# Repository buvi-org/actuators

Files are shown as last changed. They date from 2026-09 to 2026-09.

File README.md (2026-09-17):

# Primeform Robotics Actuators

We are designing and building actuators for the Primeform Robotics division, and we are doing the work in public.

This repository will hold our actuator designs and the work behind them so they are useful to our team and to others building robotics systems. As each design develops, we plan to share design files, engineering calculations, bills of materials, assembly instructions, and test results.

## Development approach

- Share work as it develops, including early designs and experiments.
- Document design decisions, tradeoffs, and lessons from testing.
- Distinguish proposed designs from built and tested hardware.
- Welcome questions, feedback, and contributions through GitHub issues and pull requests.

## AK80-9 V3.0 KV100 reference study

Our first actuator study uses the CubeMars AK80-9 V3.0 KV100 as a reference. It is an outer-rotor motor with a 9:1 planetary reducer and integrated electronics. Published CubeMars performance is a reference target, not validated performance of a Primeform build.

The Three.js workbench includes:

- A full BOM tree with selection, hierarchical visibility, isolation, focus, and a details inspector showing specifications, sources, and unresolved information.
- The manufacturer reference contains 43 CAD instances. The combined study replaces its sun blank with one gear-and-shaft solid and adds provisional stator laminations, coating faces, winding bundles, rotor yoke, magnets, gears, pins and electronics. Manufacturer bearings and fasteners remain selectable.
- An **Internals** preset and a **Gear train** preset that exposes a toothed sun, three planets and the internal ring. The 20/70/160 tooth counts produce exactly 9:1 with the ring fixed; all three gear types use involute flanks from the STEP solids. The candidate module is 0.3 and pressure angle 20°. Manufacturing release still requires process, tolerances and strength validation.
- A Primeform housing variant with screw bosses extended to the floor, a downloadable solid STEP, and a visible warning for the measured clash with the provisional rotor yoke. Toggle the gold support material to compare the source housing. See [housing study](docs/HOUSING-STUDY.md).
- Choice C: a compact ring OD locates a Ø60-bore stator radially; a housing shoulder stops it axially. [Alternatives and decision](docs/PACKAGING-CHOICES.md). **Stator mount** exposes the joint; see [mounting design and checks](docs/STATOR-MOUNT.md).
- Single-solid sun, planet and ring gear STEP files; a gear-train STEP with five gear components (one sun, three planets, one ring). Teeth are integral geometry, never assembly components. The sun preserves source end journals and replaces its middle section; its viewer mesh is tessellated from that same solid. Rebuild with `python cad/build_gears.py`; the viewer uses meshes tessellated from the same solids.
- Full assembly GLB export, including reference geometry and annotated provisional bodies. The separate Lamination lab remains independently configurable; its settings do not currently change the assembly study.
- A 35-line engineering BOM distinguishing source CAD, published data, illustration inferences and unresolved items. External mating cables are documented under the power/CAN and UART connectors, without separate internal BOM quantities or cable geometry.
- An inventory of 205 driver-board reference designators and package-model labels. Component values and exact IC part numbers remain unknown. These inventory entries are selectable data records; individual PCB positions are not mapped to the actuator assembly, so their visibility controls are disabled.
- An original, provisional lamination study with individually selectable steel sheets and two coating layers per sheet, editable profile dimensions, coating/gap/tolerance calculations, and live study quantities.
- GLB, DXF, JSON and default solid STEP deliverables.

**This is a reference and design study, not a manufacture-ready AK80-9 clone.** The manufacturer STEP omits the working motor stack and planetary internals. The lamination profile is an independently authored placeholder; only its default 36-slot count comes from the manufacturer specification.

### Run the workbench

Requires Node.js 22.12+ or a compatible newer release (tested with Node 24).

```sh
npm ci
npm run dev
```

Open `http://127.0.0.1:5173/`. Use `#lamination` to open the individual-sheet study directly. The viewer uses local Three.js/model assets; Google Fonts is optional and falls back to system fonts.

```sh
npm test
npm run build
npm run preview
```

Browser interaction checks: run the dev server, then `npm run test:browser`. The default browser is installed Microsoft Edge; set `BROWSER_CHANNEL=chrome` to use Chrome. Test outputs stay in ignored `tmp/qa/`.

### Design and evidence files

| Item | Location |
|---|---|
| Engineering BOM | [docs/BOM.md](docs/BOM.md) |
| Per-component specifications | [docs/COMPONENT-SPECS.md](docs/COMPONENT-SPECS.md) |
| Internal structure findings and questions | [docs/INTERNAL-STRUCTURE.md](docs/INTERNAL-STRUCTURE.md) |
| Electronic reference-designator inventory | [docs/DRIVER-INVENTORY.md](docs/DRIVER-INVENTORY.md) |
| Lamination equations and manufacturing limits | [docs/LAMINATION-STUDY.md](docs/LAMINATION-STUDY.md) |
| Source register and attribution | [docs/SOURCES.md](docs/SOURCES.md) |
| Reference GLB and part manifest | [public/models/](public/models/) |
| Original provisional sheet and stack STEP/DXF | [public/design/](public/design/) |
| Machine-readable BOM and specifications | [public/data/](public/data/) |

### Rebuild CAD and engineering data

Python 3.11 is tested. Install CAD dependencies in your chosen environment:

```sh
python -m pip install -r cad/requirements.txt
python cad/build_reference.py
python cad/extract_driver_inventory.py
python scripts/build_bom.py
npm run lamination
```

The first two commands download the manufacturer's ZIP files into ignored `tmp/reference/`. The conversion preserves source occurrence IDs, records the STEP hash, transforms the assembly to a centred coordinate system and converts millimetres to metres for GLB. Visual colours and explosion offsets are our annotations.

To make solid CAD for a changed lamination configuration, export **Study JSON** from the webview, then run:

```sh
python cad/build_lamination.py path/to/lamination-study.json
```

This updates the generated STEP files in `public/design/`. Browser **Stack GLB** always exports the current full assembly at true thickness, independent of display spread or the selected-sheet view. It uses metres; STEP and DXF use millimetres.

See [involute gear design and manufacturing release requirements](docs/GEAR-DESIGN.md) for the matched candidate, equations, checks and unresolved inputs.

## Licensing

The repository is public. Licenses for Primeform's hardware studies, software and documentation have not yet been selected; public access alone does not grant a license to reuse those materials. Manufacturer reference geometry remains attributed to CubeMars. It is not an original Primeform design or covered by a Primeform open-hardware license. See [source attribution](docs/SOURCES.md).

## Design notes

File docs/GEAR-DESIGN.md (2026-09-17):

# Involute planetary candidate — 9:1

This replaces the polygonal placeholder teeth with an analytically defined involute candidate. It is an original Primeform gear design, not a recovered CubeMars tooth specification. Manufacturing release is pending; a CAD curve cannot establish 100% physical manufacturing accuracy.

| Parameter | Sun | Planet (three) | Internal ring |
|---|---:|---:|---:|
| Teeth | 20 | 70 | 160 |
| Module, mm | 0.3 | 0.3 | 0.3 |
| Pressure angle | 20° | 20° | 20° |
| Profile shift | 0 | 0 | 0 |
| Pitch diameter, mm | 6 | 21 | 48 |
| Tip diameter, mm | 6.6 | 21.6 | 47.4 |
| Root diameter, mm | 5.25 | 20.25 | 48.75 |
| Face width, mm | 7.5 | 5 | 5 |
| Circular tooth thinning, mm | 0.010 | 0.010 | 0.010 |

The candidate preserves the previous pitch diameters and 13.5 mm planet centre radius. The standard unshifted 20° undercut limit is 2/sin²(20°) ≈ 17.10 teeth; the 20-tooth sun clears it. The previous 12-tooth sun did not, and cannot simply be given an unshifted full-depth involute without addressing undercut.

With the ring fixed, sun input and carrier output, i = 1 + Zr/Zs = 1 + 160/20 = 9 exactly. Geometry closes because Zr = Zs + 2Zp = 160. Three equally spaced planets are possible because (Zs + Zr)/3 = 60 is an integer. Changing which member is fixed changes the ratio.

## Curves and STEP

`cad/involute_geometry.py` defines the flanks from the involute function, inv(alpha) = tan(alpha) - alpha, and the base radius. Each flank uses a parameterized interpolating B-spline with 49 analytic samples; 193 independent evaluation positions per representative flank check the fit. The enforced sampled position-error bound is 0.000001 mm. This is a numerical CAD check, not a manufacturing tolerance or a rigorous bound between every sample. STEP uses curved edges, not polygonal tooth flanks.

Root transitions use 0.060 mm circular fillets. The sun includes the below-base-circle radial transition; the planet and ring use tangent circular root blends. These fillets are explicitly designed geometry, not a claim about the trochoidal root left by a hob or shaper. A cutting process/tool definition may require different roots. Tip relief, lead correction and crowning are not yet specified.

Each gear is one valid solid. The sun preserves the source end journals, replacing the central section from z = 3.75 to 11.25 mm. The common mesh plane is z = 8.25 mm. STEP files are exported and re-imported to verify validity, solid count and volume. The browser loads tessellations of the same solids for all three gear types. The manufacturing surface is the STEP B-rep, not the GLB triangles.

## Checks and their limits

`public/design/gear-validation.json` records solid and spline-fit checks. `public/design/gear-mesh-validation.json` records:

- Exact 9:1 kinematic ratio and matching 13.5 mm centre distances.
- External transverse contact ratio ≈ 1.682; internal ≈ 1.947, from standard unmodified addendum geometry.
- Correct planet/ring phasing and zero detected overlap in 720 sampled positions across one full carrier revolution (nine sun revolutions), using sampled actual CAD boundaries.
- Nominal 0.020 mm circular backlash per mesh, obtained by thinning each mating tooth by 0.010 mm at its pitch circle. This is a candidate nominal allowance, not a backlash tolerance range or a verified output lost-motion figure.

The motion check is finite planar sampling, not proof at every continuous position, cutter simulation, or loaded contact analysis. It excludes carrier/pin deflection, runout, tolerance stacks, temperature, lubrication and torque-dependent elastic deformation. The existing housing/rotor conflict remains separately unresolved.

## Required before manufacturing release

Choose cutting process, tooling and root generation; material and heat treatment; tooth-thickness/space-width tolerances and measurement method; gear quality, profile/lead deviations and runout limits; bearing and shaft fits; chamfers and burr removal; lubricant; rated/peak duty and life. Complete tooth bending/contact fatigue, load sharing, shaft/root/fillet strength, cutter interference, and loaded contact checks. The original product's torque ratings do not validate this finer-module candidate.

Rebuild: `python cad/build_reference.py` if source cache is absent, then `python cad/build_gears.py` and `python cad/check_gear_mesh.py`.

Sources: [Drivetrain Hub — spur gear geometry](https://drivetrainhub.com/notebooks/gears/geometry/Chapter%202%20-%20Spur%20Gears.html), [planetary assembly conditions](https://drivetrainhub.com/notebooks/gears/geometry/Chapter%204%20-%20Planetary%20Gears.html), [KHK — internal gear interference](https://khkgears.net/pdf/internal-tech.pdf). Equations were checked against these references; the candidate values are Primeform assumptions.

The ring now uses a compact Ø59.96 locating rim without the long stator sleeve; see [stator mounting revision](STATOR-MOUNT.md). The tooth geometry and ratio are unchanged.

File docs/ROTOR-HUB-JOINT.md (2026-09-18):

# Rotor hub / end bell joint audit — measurement record

Prepared 2026-09-17 against baseline `dd09154`. Reproduce with:

```powershell
python cad/check_hub_joint.py
```

Output: `public/design/hub-joint-validation.json`. Source geometry is the
manufacturer STEP revision recorded by `manifest.source_sha256`; the checker
asserts that hash before measuring, so these numbers cannot silently drift from
the reference model.

This replaces the arithmetic in the handoff. Everything below is a measurement of
the source CAD in the assembled, centred millimetre frame, or an explicit
statement that the measurement is impossible with the current modelled geometry.

## 1. What the OEM input-shaft hub actually is

Occurrence `NAUO45` (`AK80-9输入轴-2`), mapped in the BOM as `G03` "Input shaft
hub". Measured, it is **a body of revolution about the motor axis**, not a disc
with a bore. The X-Z material section is:

| z range (mm) | material radius (mm) | feature |
|---|---|---|
| -9.250 … -8.750 | 3.0, 5.55 … 5.95 | rear lead-in |
| -8.750 … -6.750 | 3.0, 6.0 | rear land, Ø6 bore |
| -6.750 … -3.250 | 2.0, 6.0 | Ø4 bore, Ø12 outer |
| -3.250 … -2.750 | 2.0, 7.0 | Ø14 shoulder |
| -2.750 … -1.750 | 2.0, 17.145 | flange back face, Ø34.29 |
| -1.750 … +0.250 | 2.0, 18.975, 21.025, 22.25 | spoked flange: Ø35.5 pocket, Ø42.05 rim, Ø44.5 outer |
| +0.250 … +1.250 | 2.0, 7.0 | Ø14 collar |
| +1.250 … +3.250 | 2.0, 6.0 | front land |
| +3.250 … +4.750 | 2.975, 6.0 | front counterbore Ø5.95 |
| +4.750 … +5.250 | 2.975, 5.55 … 5.95 | front lead-in |

Key numbers:

- Outer envelope Ø44.5, length 14.5 mm, volume 3114.2 mm³ (matches the manifest).
- Flange: r 17.145 → 22.25 mm (Ø34.29 → Ø44.5) over z -1.75 → +0.25 mm, so the
  web is **2 mm thick** with six spokes, a Ø35.5 annular pocket and a Ø42.05 rim.
- Bores: a 12 mm counterbore (see below), a Ø4 middle bore, a Ø6 rear bore and a
  Ø5.95 front counterbore.
- A Ø2.546 mm cylindrical face runs z -6.75 → +3.25 mm: the through-bore.

## 2. It is coaxial with the sun and carries both bearings

Boolean interference against the neighbouring occurrences (mm³):

| pair | interference | reading |
|---|---:|---|
| hub `NAUO45` ↔ sun `NAUO41` | 0.324 | coaxial, nominal line-to-line contact only |
| hub ↔ 6701-ZZ rear `NAUO42` | 0.000 | coaxial, no interpenetration |
| hub ↔ 6701-ZZ front `NAUO43` | 0.000 | coaxial, no interpenetration |
| hub ↔ encoder target magnet `NAUO44` | 0.000 | coaxial, no interpenetration |
| hub ↔ rear housing `NAUO4` | 0.000, min distance 0.500 | clears the housing |
| hub ↔ main housing `NAUO3` | 0.000 | clears the housing |

The STEP hierarchy confirms the grouping: one subassembly holds `NAUO41` (sun),
`NAUO42`/`NAUO43` (both 6701-ZZ), `NAUO44` (encoder magnet) and `NAUO45` (hub).
The hub is the bearing carrier of that coaxial module. It is **not** an outboard
end-bell disc that a hub bolts onto.

## 3. Why assembly step A06 attaches nothing

The viewer's rotor shell is procedural and does not share this form.

| | procedural `EM03/endbell` | measured OEM hub |
|---|---|---|
| form | plain annulus | body of revolution, six-spoke flange |
| opening / envelope | 46 mm opening (r 23) | Ø44.5 envelope (r 22.25) |
| z band | -8.6 … -7.6 mm | flange at -1.75 … +0.25 mm |

Three independent defects, each sufficient on its own:

1. **No contact.** The end-bell band and the hub flange band do not intersect in
   z at all — they are 6.85 mm apart at the nearest faces.
2. **No receiving surface.** Even if the two were brought into one plane, a 46 mm
   opening cannot receive a 44.5 mm body as a fit; the end bell has no bore, land,
   shoulder or counterbore sized for the hub.
3. **Wrong form.** The OEM part is a revolution body with a spoked flange; the
   procedural part is a flat annulus. Replacing one with the other is a geometry
   change, not a dimension tweak.

The rotor shell is not joined to itself either: `EM03/endbell` ends at z -7.6 mm
and `EM03/yoke` begins at z -7.5 mm, a modelled 0.1 mm axial gap. Sharing parent
`EM03` in the tree connects nothing.

**Conclusion.** A06 previously read "Attach input hub to rotor end bell" with
status "Proposed / requires validation". No attachment geometry, retention or
torque path existed. It is now marked `Blocked by known geometry`, and autoplay
stops on it instead of overshooting to A07.

## 4. The drive interface the CAD does encode

Sectioning the sun across the contact band and classifying each section (plain
loop vs azimuthal radius spread vs loop count) resolves the earlier open question:

| Measurement | Value |
|---|---|
| Contact volume | 0.324 mm³ |
| Contact axial band | z 3.750 … 5.250 mm |
| Fit at that band | sun front journal Ø6.000 into hub counterbore Ø5.950 |
| Sun section across the band | one loop, r 2.4185 … 3.000 |
| Azimuthal radius spread | **0.2022 mm** → a keyed or flat (D) drive feature |

So the hub does not merely retain the sun on bearings: its front counterbore
pilots the sun's keyed front journal over 1.5 mm of engagement. That is the
measured torque path from the rotor side into the sun, and it is why the earlier
"friction through two bearings" reading in this document was wrong.

**Caveat.** A 0.202 mm azimuthal spread measured from a CAD tessellation is
evidence of a drive feature, not a released key or spline specification. Confirm
it against hardware before designing to it.

No key, keyway, spline or cross-pin appears anywhere on the sun's rear Ø4.0
section.

## 5. What was implemented

1. **The real hub is in the model.** `cad/build_hub.py` re-exports occurrence
   `NAUO45` from the source STEP as `public/design/oem-rotor-hub.step` and
   `public/design/oem-rotor-hub.glb` (one valid solid, 3114.2 mm³, Ø44.5 × 14.5).
   The viewer shows it as assembly item `G03`, replacing the procedural
   `EM03/endbell` and `EM03/yoke` annuli, which have been deleted.
2. **The hub joint is described from measurement.** Assembly step A06 now names
   the actual surfaces: the Ø5.95 counterbore onto the sun's Ø6.0 keyed journal
   over z 3.75…5.25 mm, plus the Ø12 and Ø6 bearing bores and the encoder-magnet
   seat.
3. **The stator shift was reversed.** The rotor's axial position is fixed by real
   OEM features (the hub, both 6701-ZZ bearings, the encoder magnet), so the
   Choice C **+4.5 mm stator shift was the error**. The stator, winding, ring
   mounting flange and housing seat all moved 4.5 mm rearward, so the 13.872 mm
   steel stack now spans z −6.936…+6.936 mm and overlaps the full magnet span
   (−7…+7 mm) instead of 9.436 mm. The gear mesh itself is deliberately unchanged:
   the sun stays on the OEM shaft journals.
4. **Reports and data were regenerated**, not hand-edited: `build_gears.py` and
   `build_housing.py` now derive everything from a single `SHIFT` constant, and
   `stator-mount-validation.json`, `housing-study.json` and
   `packaging-choice.json` follow.

## 6. What is still blocked, and why

A06 remains `Blocked by known geometry`, for a different and better-understood
reason than before.

The hub's flange ends at **r 22.25 mm**. The nearest housing wall is at
**r 47.4 mm**. That is a **25.15 mm radial gap**, and the source CAD contains no
web, spider, bell or disc joining the hub to the rotor shell. So:

- The hub **is** measured, correctly shaped and correctly placed.
- The **hub-to-sun joint is real** and measured.
- The **hub-to-rotor-shell joint does not exist in the evidence**. Until it is
  designed, the hub has no rotor torque input and A07 has no rotor to install.

Two further open items:

1. **Rotor radial placement.** The study yoke (r 42.5…45.5) and magnet band
   (r 40.5…42.5) do not coincide with the arcuate slots in the source housings
   (r 41.766…43.236). The housings' slots do not match the study's 42-segment
   band either, so the source model does not settle where the magnets belong.
2. **The housing-boss clash.** The added supports still intersect the provisional
   yoke by 1134.581 mm³. It is unchanged by the axial realignment, because the
   yoke spans z −7.5…+7.5 and the supports run the housing floors.

## 7. Next correction, in order

1. Design and validate the hub-to-shell connection that closes the 25.15 mm gap,
   or establish from hardware that the OEM achieves it with a feature absent from
   the published STEP.
2. Resolve the rotor radial envelope so the yoke clears the housing bosses and the
   magnets sit on a justified radius.
3. Release the Ø5.95/Ø6.0 keyed pilot fit: fit class, retention, runout, balance
   and torque capacity against the 9:1 gearbox input.

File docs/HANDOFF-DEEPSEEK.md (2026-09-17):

# Handoff to DeepSeek — Primeform actuator CAD and assembly viewer

Prepared 2026-09-17. Technical baseline commit: `332871a` on `main`.

## Read this first

The user is dissatisfied with the mechanical reasoning and validation. They are handing this work over, not asking for more cosmetic changes from the previous agent. The latest concrete failure is **Assembly process step 6: the input shaft hub is suspended inside the rotor end bell with no modeled connection**. The previous agent had just begun investigating it when the user requested this handoff. No corrective geometry, contact measurement, or full visual audit was completed after that complaint.

The project is **not a mechanically complete actuator**, despite having a substantial viewer, BOM, generated STEP files, and passing software tests. Several parts are illustrative proxies. “Proposed / requires validation” labels do not excuse physically meaningless assembly operations. Do not treat the current sequence, zero-overlap checks, or valid STEP solids as proof of assemblability.

Working tree was clean at handoff start. This handoff is the only intended new change after baseline `332871a`.

## Project and environment

- User: Rajesh. Organization: Primeform Robotics; public engineering repository under buvi-org.
- Repository: https://github.com/buvi-org/actuators
- Windows workspace: `C:\Users\Rajesh\Documents\ChatGPT\actuators`
- Branch: `main`; previous work committed and pushed directly there with the user's prior authorization.
- Viewer: http://127.0.0.1:5173/#model (Vite server has been running locally; check before starting another).
- Frontend: Vite 8.3.0, Three.js 0.186.0, plain JavaScript.
- Node 24 was used. Python 3.11 with CadQuery 2.7.0, trimesh 4.11.2, shapely 2.1.2, scipy and numpy; see `cad/requirements.txt`.
- Playwright 1.58.2 tests use installed Microsoft Edge (`channel: msedge`).
- `tmp/`, `node_modules/`, `dist/`, Python caches and `.venv/` are ignored. Local diagnostic files in `tmp/` are not portable repository dependencies.

## User's objective and requirements

Create an open AK80-9 V3.0 KV100 actuator design for Primeform Robotics: complete physical assembly, individual laminations/coatings, gears, rotor, stator, windings, magnets, bearings, fastening, BOM/specifications and Three.js visualization. Internal assumptions must be distinguished from manufacturer evidence.

Persistent user requirements:

1. Preserve CubeMars external dimensions and mounting interfaces. Do not solve internal problems by arbitrarily enlarging the exterior or drastically thinning one feature.
2. Every physical part must be selectable and visibility-controlled through the BOM tree, with all known details in the inspector.
3. Each gear is one physical part and one STEP solid. Teeth are not separate tree items or separate manufactured parts.
4. Individual laminations must be represented; allow steel/coating/stack-count studies.
5. Do not add duplicate external harnesses when connectors already represent the interface.
6. Assembly steps must say exactly which part is fitted to which receiving part, on which surfaces, and by what process.
7. Parts must not pass through other solid parts. Treat subassemblies as retained groups once their connections exist.
8. Call the mode **Assembly process**, not Joint review.
9. Parts are opaque and have distinct, stable colors. No section cuts inside Assembly process.
10. Earlier installed parts stay visible; separate bench preparation retains earlier members of that subassembly.
11. Step navigation/playback must preserve camera orbit, pan and zoom. Only explicit Fit step (or ordinary viewer Fit) reframes.
12. Inspect actual rendered outputs and mechanical interfaces, not only code and UI assertions.

## Immediate failure: step A06, hub to rotor end bell

Current A06 says “Attach input hub to rotor end bell,” but no attachment geometry or method is implemented.

- G03 is OEM reference occurrence `NAUO45`, one source solid. Manifest bounding box in assembly mm: x/y ±22.25; z -9.25 to +5.25. Envelope Ø44.5 × 14.5 mm. Bounding dimensions do not identify the actual contact surfaces or usable cylindrical lands.
- EM03/endbell is a procedural annulus: inner radius 23 mm, outer radius 45.5 mm, thickness 1 mm, center z -8.1 mm; axial span -8.6 to -7.6 mm.
- Therefore the displayed bell opening is Ø46 mm, larger than the hub's Ø44.5 nominal envelope. A nominal 0.75 mm radial mismatch is suggested for circular envelopes, but **no exact CAD minimum-distance/contact-face measurement was performed**. Inspect the real hub profile.
- EM03/yoke is a separate procedural annulus, radii 42.5–45.5 mm, z -7.5 to +7.5 mm. The bell ends at -7.6 mm, suggesting an additional **0.1 mm axial disconnection** between bell and yoke. This is arithmetic from the modeled extents, not an executed CAD audit.
- Sharing parent `EM03` in the tree does not join those solids mechanically.
- A06 is still incorrectly treated as an ordinary proposed stage; autoplay does not stop there. It first stops at A07, which is marked blocked.
- The hub is not proven to transfer torque to either the bell or sun shaft. Do not “fix” it merely by enlarging overlapping geometry, changing colors, or attaching a warning. Define actual receiving surfaces, retention and torque transfer, then check fit and access.

Recommended first investigation: render A06 from multiple sides, inspect source hub faces in STEP, measure separations, identify intended torque path and feasible connections within the fixed envelope, and check any proposed correction against the rear housing, bearings and stator winding space. Coordinate with the rotor axial-layout problem below.

## Current selected packaging: Choice C

The user asked to document options and provisionally choose one. Implemented in baseline `332871a`. Read `docs/PACKAGING-CHOICES.md` and `docs/STATOR-MOUNT.md`.

| Parameter | Current study value |
|---|---:|
| External reference envelope | Ø98 × 38.5 mm |
| Stator OD / bore / slot-root diameter | 80 / 60 / 68 mm |
| Radial stator back iron | 4 mm |
| Radial tooth region, including tip | 6 mm |
| Steel sheets | 68 × 0.20 mm |
| Coating | 2 micrometres per face |
| Gross stator stack | 13.872 mm |
| Stack center / ends | z 4.5 / -2.436 to +11.436 mm |
| Ring locating OD | 59.96 mm |
| Nominal radial bond gap | 0.020 mm |
| Ring full axial span | z 5.75 to 13.25 mm |
| Ring toothed band | z 5.75 to 10.75 mm |
| Ring/stator axial overlap | 5.686 mm |
| Main housing stator shoulder | z 11.436 mm, radii 30.1–33.5 mm |
| Winding proxy | radii 34.5–39 mm; z -3.3 to +12.3 mm |
| Eight front screws | M2.5 × 6, Ø54 PCD, tips z 9.95 mm |
| Nominal penetration from ring mounting face | 3.3 mm, not qualified thread engagement |
| Ring material beyond screw thread major diameter | approximately 1.73 mm |

User-approved locating concept: **ring OD provides stator radial location; housing shoulder provides axial stop**. Adhesive retention is only an unqualified proposal, not an approved fit/process.

The old Ø52 stator bore and Ø62 slot-root diameter were arbitrary initial defaults, not CubeMars measurements. They were mistakenly treated as fixed constraints in earlier reasoning. Choice comparisons retain Ø80 stator OD:

- A: bore 56, root 64 → 4 mm back iron, 8 mm radial tooth region; existing Ø54/M2.5 screw pattern breaks through a nominal Ø56 rim.
- B: bore 58, root 66 → 4 mm back iron, 7 mm tooth region; only 0.75 mm nominal outer screw-edge material before fit allowance.
- C: bore 60, root 68 → 4 mm back iron, 6 mm tooth region; selected for better existing screw packaging.

These are packaging comparisons, not electromagnetic optimization. Slot area, wire/turn count, saturation, iron/copper loss, strength and temperature have not been validated.

Choice C removed the long ring sleeve and its stator shoulder. The ring still has a front mounting rim extending **1.814 mm beyond the steel stack axially**. The entire ring fits radially inside the bore, but complete axial containment of the ring was NOT achieved. The tooth band is axially contained. This deviation is documented, not solved.

## Known mechanical problems and missing design

1. **Hub/end-bell and bell/yoke disconnections:** latest complaint, described above; not yet fixed.
2. **Rotor yoke vs housing bosses:** sixteen added Ø5 screw supports intersect the provisional yoke. Reported overlap approximately 1134.581 mm³. `cad/build_housing.py` and `public/design/housing-study.json`.
3. **Rear housing vs end bell:** reported overlap 2666.283256 mm³ with OEM NAUO4. `cad/check_rotor_clearance.py`, `public/design/rotor-clearance-validation.json`. The script/report contain OLD stator/winding positions (-6.936 and -7.8) and must be updated before drawing coordinated-layout conclusions. Bell and rear geometry remain unchanged, so the old collision remains relevant.
4. **Rotor axial alignment after Choice C:** stator moved +4.5 mm; rotor/magnets did not. Magnet span remains -7 to +7 mm, giving only 9.436 mm axial overlap with the shifted steel. Do not claim motor ratings from this arrangement.
5. **Stator retention:** ring overlap is only 5.686 mm, radial nominal gap 0.020 mm. Adhesive, tilt/runout control, torque capacity, cure, thermal path and sheet-stack retention remain unresolved.
6. **Windings and insulation:** coil bundles, solid liner envelopes and resin extent are illustrations. Shortening the radial coil bundle to fit the new roots does not prove windability, slot fill or electrical performance. Liner proxies may overlap parts and cannot be treated as detailed manufactured insulation.
7. **Planet carrier/pins/supports:** carrier is source geometry, but pin bores, retention and actual bearing/bushing selection are unresolved. Simply positioning pins and planets does not create a load-bearing carrier.
8. **Bearing ownership and retention:** exact inner/outer race mating seats, shoulders, fits, preload/endplay and assembly order need to be established for B01/B02/B03.
9. **Sun/hub connection:** torque-transfer and axial retention undefined.
10. **Electronics:** board mounts, thermal path, lead termination, capacitor placement/retention, encoder gap and routing are not released. 205 driver designators are inventory data; most physical positions are unmapped.
11. **Seals, shims and grease:** placeholder geometry; no completed groove, shim/preload, quantity or lubrication design.
12. **All insertion paths:** no full swept-volume and tool-access validation exists. The current 20-stage order is proposed, not established.

## What is actually checked

Last completed work before handoff:

- Generated ring and modified main housing each valid as one CAD solid.
- Ring STEP export/re-import valid; five-gear STEP assembly has five solids, not individual tooth solids.
- Ring nominal overlap checks against selected source bodies and stator/winding annular envelopes returned zero. See `public/design/stator-mount-validation.json` for the exact limited pair list.
- New housing shoulder vs stator/winding/ring annular envelopes returned zero overlap.
- A local check in ignored `tmp/check-choice-c.py` found modified housing vs compact ring overlap zero and unchanged housing bounding box in all six limits. This check is not yet a durable committed regression script.
- Existing gear profile study includes analytic involute generation and a sampled planar mesh-interference audit; it does not qualify gear strength, tolerances, root manufacturing process or installation paths.
- `npm test` (13 tests), `npm run test:assembly`, `npm run test:browser`, and `npm run build` passed after Choice C updates.

**Limits:** software tests check controls, visibility, color identity, unchanging positions, camera behavior, BOM references, exports and layout. They do not verify that each component is attached, that subassemblies transmit loads, or that a plausible rendered step is mechanically meaningful. Prior green tests did not catch the unsupported hub.

Prior visual QA viewed selected screenshots, not a systematic inspection of every stage from suitable angles. A full visual/contact audit has not happened. Do not repeat that omission.

## Viewer and assembly process implementation

- `src/main.js`: scene/loading, tree, inspector, selection, visibility, tabs, exports, render loop. `window.__actuator` exposes model, meshes, assembly nodes, camera, selection and assemblyGuide for browser inspection.
- `src/assembly-model.js`: procedural internals and source-node mapping. Most dimensions are hardcoded. Mesh `userData.nodeId`, `basePosition` and `explode` drive identity and placement.
- `src/assembly-guide.js`: Assembly process stage display, stable part colors, local bench context and prior installed context. No physical insertion trajectory is animated.
- `public/data/assembly-sequence.json`: 20 proposed stages, moving/receiving IDs, contexts, surfaces, process, checks and path-review text.
- Playback alternates before/after visibility states. It does not interpolate part positions. Known blocked steps stop automatic progression. Manual later previews remain possible.
- No section cuts in process mode; global Section control is hidden while active. Earlier parts remain opaque. Fit step is explicit; step changes must not reset the camera.
- Main housing source mesh and added geometry share a physical color identity. Other physical node IDs get stable distinct colors. Data-only descendants have no geometry.
- Full assembly GLB export uses base positions, not the currently displayed stage or exploded state.

Current stage order:

1. Main housing.
2. Ring/radial locator into housing.
3. Eight front screws.
4. Prepared stator onto ring OD and housing stop.
5. Rotor bench: magnets and adhesive into yoke.
6. Rotor bench: hub into end bell — **invalid attachment, latest complaint**.
7. Rotor subassembly into actuator — known clash/blocker.
8. Input bearings and sun — receiving seats unresolved.
9. Carrier bench: pins to carrier.
10. Carrier bench: supports and planets.
11. Output bearings.
12. Carrier/planet group installation.
13. Lubricant and closure materials.
14. Rear housing — known clash/blocker.
15. Sixteen rear screws — blocked by closure.
16. Encoder target magnet.
17. Populated driver board.
18. Driver cover.
19. Six driver-cover screws.
20. Output closure cover.

## CAD, data and source map

- `public/models/manifest.json`: source identity, BOM mapping, normalized mm bounding boxes, original center and source SHA. Source CAD has 43 leaf instances; original sun blank is excluded/replaced in viewer, leaving 42 source meshes plus added geometry.
- `public/models/ak80-9-reference.glb`: unchanged manufacturer reference conversion.
- `cad/build_reference.py`: obtains/converts OEM source; local source cache `tmp/reference/reference.step` is ignored.
- `cad/build_gears.py`: compact ring, eight mounting bores, source-journal sun with replaced teeth, planets, STEP and GLB exports, limited mounting validation.
- `cad/involute_geometry.py`: 20/70/160 teeth, module 0.3, 20° pressure angle, no profile shift, 0.01 mm tooth thinning per gear, 0.06 mm circular root fillets. Those fillets are not generated hob/shaper trochoids.
- `cad/check_gear_mesh.py`: sampled planar mesh audit. Ring fixed / sun input / carrier output gives 9:1. Three planet centers radius 13.5 mm, gear plane z 8.25 mm.
- `cad/build_housing.py`: preserves source main housing, adds sixteen long screw bosses and Choice C stator shoulder; exports whole modified STEP and added-material GLB for overlay on source mesh.
- `src/lamination-math.js`: default 60 mm bore / 68 mm roots and profile/stack mathematics. `src/lamination-view.js`: independent lab. Lab edits do not automatically update the full assembly.
- `scripts/export-lamination.mjs`, `cad/build_lamination.py`: default profile/DXF/STEP stack. Standalone stack is at local origin; assembly applies +4.5 mm.
- `scripts/build_bom.py`: generator for `public/data/bom.json`, `docs/BOM.md`, `docs/COMPONENT-SPECS.md`. Update generator as well as outputs.
- `public/data/packaging-choice.json`: chosen dimensions, but **not yet a single source driving all CAD/JS**. Values are duplicated across generators, JS, reports and process data. Synchronize explicitly or refactor carefully.
- `docs/PACKAGING-CHOICES.md`: current decision, alternatives, trade-offs, partial checks.
- `docs/STATOR-MOUNT.md`, `docs/HOUSING-STUDY.md`, `docs/GEAR-DESIGN.md`, `docs/INTERNAL-STRUCTURE.md`, `docs/LAMINATION-STUDY.md`: design context. Historical sections and scripts can contain superseded assumptions; current geometry takes precedence for measurement, not for validation.

Units: CAD and documented coordinates are mm; GLB/Three.js positions are metres. Procedural helpers in assembly-model generally accept mm and convert. Source positions are centered using manifest `center_original_mm`. Gear assets use local z=0 corresponding to assembly z=8.25 mm. Ring phase is π/160; its bolt holes are compensated in generator coordinates. Preserve these transforms when comparing solids or replacing geometry.

## Source evidence

- Product: https://www.cubemars.com/product/ak80-9-v3-0-robotic-actuator.html
- Drawing: https://www.cubemars.com/data/cms/202602/ak80-9-v3-0-robotic-actuator-2d-drawing.pdf
- STEP: https://www.cubemars.com/data/cms/202602/ak80-9-v3-0-robotic-actuator-3d-drawing.zip
- Manual: https://www.cubemars.com/data/cms/202602/ak-series-prodcut-manual-v3-2-0-for-ak-3-0-robotic-actuator.pdf
- Exploded illustration: https://img.cubemars.com/products/AK70_80/images/AK80-9_02.jpg
- Source register: `docs/SOURCES.md`.

Published 36 slots, 21 pole pairs, 9:1 ratio, 100 KV and exterior dimensions do not establish internal lamination dimensions, tooth counts, magnet piece count or assembly joints. Current 42 separate magnet pieces are an assumption: 42 poles does not prove 42 pieces. Published torque/current/thermal ratings belong to CubeMars hardware, not this study.

## Running and rebuilding

```powershell
npm install
python -m pip install -r cad/requirements.txt
npm run dev
```

If source STEP is absent, inspect/run `python cad/build_reference.py`. Preserve the manufacturer reference when rebuilding study geometry.

```powershell
python cad/build_gears.py
python cad/build_housing.py
python scripts/build_bom.py
npm run lamination
python cad/check_gear_mesh.py
npm test
npm run test:assembly
npm run test:browser
npm run build
```

Update `cad/check_rotor_clearance.py` for the current layout before using its coordinated-placement conclusions. Keep stdout/results from mechanical checks. Source STEP import/generation can take tens of seconds.

## Suggested continuation and acceptance criteria

1. Reproduce A06 visually, rotate to see the actual separation, and inspect hub/bell/yoke CAD surfaces. Record exact measurements and the missing torque path.
2. Audit **every stage**, not just A06: receiving parts present, correct physical subassembly membership, actual contact where intended, no accidental penetration, defined retention and access. Save labeled views and a finding table. Add connection checks, not only collision checks: zero overlap can mean a part is floating.
3. Resolve rotor/hub/end-bell design together with the shifted stator, magnets, bearings and housing bosses. Keep the external interfaces fixed. Present concrete joint proposals rather than silently assuming a press fit, weld or screw joint.
4. For each proposal, synchronize procedural viewer geometry, STEP, BOM/specifications, process steps and validation reports. Missing features must remain clear failures, not successful “attach” steps.
5. Check both static assembly and installation path/tool access. Only enable physical motion after defining and testing the moving group and stationary assembly state.
6. Render the actual changed output from multiple useful viewpoints. Re-run mechanical checks and UI tests for their distinct purposes. Report remaining failures honestly.

The prior agent's key errors were generic through-solid motion, treating proximity or shared tree parenting as assembly, assuming a bore without evidence, and claiming useful completeness from UI/build checks. The handoff should help replace those shortcuts with demonstrable mechanical connections and observed results.

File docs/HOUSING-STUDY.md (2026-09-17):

# Main housing R1: supported screw bosses

Current R2 adds the Choice C stator axial seat at z 11.436 mm, radii 30.1–33.5 mm. See [packaging decision](PACKAGING-CHOICES.md). Original R1 boss discussion follows; its rotor interference remains unresolved.

The CubeMars NAUO3 housing remains the reference. Primeform R1 extends sixteen 5 mm diameter screw supports toward the housing floor, centred on the source screw axes. Gold support bodies in the tree show the added material; hiding them restores the reference view. They are integral housing material, not additional purchased parts.

`cad/build_housing.py` generates the modified solid STEP, the added-material GLB, and `public/design/housing-study.json`. Run `python cad/build_reference.py` first if the cached source STEP is absent, then `python cad/build_housing.py`. Coordinates are centred assembly millimetres. The rear seating face is z = -4.75 mm and the extrusion terminates at z = 15.25 mm, reaching the existing pocket floors. Existing source screw bores are retained; this does not specify or extend thread engagement. Original material is not removed. Reference GLB and STEP attribution remain unchanged.

## Clearance finding

The extended supports overlap the current illustrative rotor yoke (ID 85 / OD 91 / length 15 mm). This is a known geometry conflict, not just an unperformed check. The modified housing is a design study; the provisional motor envelope must be reconciled before a functional assembly or machining release. Reducing the rotor diameter would affect magnets, air gap, stator dimensions and performance, so that change is not made silently. See the generated report for overlap volume.

The constant-diameter supports fill beneath the tapered rear pads. Their 5 mm diameter is a Primeform choice, not a recovered OEM dimension. This is not a complete CAM validation: root fillets, tool radii, remaining source pockets, wall thickness, fits and workholding still need review.

## Side holes

The STEP has a pair of 2.1 mm diameter radial bores on the +Y side and a pair of 3.2 mm diameter radial bores on the opposite side. Their centres are x = ±6 mm and z = 3.25 mm. These are geometric measurements, not thread callouts. The published external drawing does not label their functions. A small fixing/access interface is plausible, but mounting, retention, tooling and wiring functions are not established. Retain the holes pending confirmation; do not designate them as ventilation or cable exits.

## Spaces between bosses

The scalloped peripheral cavity leaves room around the motor envelope while retaining local material at fasteners. Compared with a continuous thick ring, it also removes material and mass. These are geometric/engineering interpretations, not an OEM statement of purpose. The shallow pockets in the housing floor are a separate feature and appear consistent with material removal while retaining ribs. Neither region is validated spare space: rotor runout, assembly insertion, thermal expansion, insulation, and any routing must be accounted for. The collision above demonstrates why filling peripheral space needs a motor-envelope check.

Sources: [CubeMars STEP](https://www.cubemars.com/data/cms/202602/ak80-9-v3-0-robotic-actuator-3d-drawing.zip), [external drawing](https://www.cubemars.com/data/cms/202602/ak80-9-v3-0-robotic-actuator-2d-drawing.pdf). No inspected source establishes the OEM manufacturing process or side-hole purpose.

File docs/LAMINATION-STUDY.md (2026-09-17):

# Individual lamination study

The purpose is to inspect every steel sheet, see how two-sided coating consumes axial space, and choose a layer count under an explicit stack budget. This does not establish an OEM winding or magnetic design.

## Default assumptions

| Parameter | Default | Evidence |
|---|---:|---|
| Slots / teeth | 36 | CubeMars product specification |
| Outside diameter | 80 mm | Provisional study dimension |
| Bore | 60 mm | Choice C provisional packaging |
| Slot-root diameter | 68 mm | Choice C: 4 mm radial back iron |
| Tooth body / tip width | 2.8 / 4.8 mm | Provisional study dimensions |
| Tooth-tip radial depth | 1.2 mm | Provisional study dimension |
| Bare steel thickness | 0.20 mm | Study assumption |
| Coating per face | 2 micrometres | Study assumption |
| Additional interface gap | 0 micrometres | Idealized packed stack |
| Available axial budget | 14 mm | Study assumption, not a measured motor stack |
| End allowance | 0 mm | Study assumption |
| Steel thickness tolerance | +/-0.005 mm | Illustrative tolerance, not a supplier guarantee |
| Coating tolerance | +/-0.5 micrometres per face | Illustrative tolerance |

The model has outward-facing teeth consistent with an outer-rotor study. The profile has no production fillets, interlocks, winding-specific slot opening, burr allowance, or validated flux path. Cutting it is not a released manufacturing instruction.

## Stack calculation

All equation terms use millimetres. Convert coating and gap inputs from micrometres by dividing by 1000.

Let `t` be bare steel thickness, `c` coating on one face, `g` additional gap/adhesive per interface, `N` the number of sheets, `B` the overall axial budget, and `a` the combined end allowance.

```text
Coated sheet thickness = t + 2c
Stack height H = N(t + 2c) + (N - 1)g
Overall height = H + a
Maximum whole-sheet count = floor((B - a + g) / (t + 2c + g))
Net axial steel = Nt
Axial steel fraction = Nt / H
Budget remaining = B - a - H
```

The outside coating faces count too: there are `2N` coated faces and `N-1` inter-sheet interfaces. For a single sheet there is no interface gap. End allowance is added once, not once per sheet. The zero-sheet case returns zero stack height.

For the default configuration: 68 sheets, 136 coated faces, 67 interfaces, 13.600 mm of steel, 0.272 mm of coating and 13.872 mm stack height. Nominal remaining budget is 0.128 mm. Geometric axial steel fraction is 98.04%.

| Coating per face | Whole sheets within 14 mm | Coated stack | Net steel |
|---:|---:|---:|---:|
| 0 micrometres | 70 | 14.000 mm | 14.000 mm |
| 1 micrometre | 69 | 13.938 mm | 13.800 mm |
| 2 micrometres | 68 | 13.872 mm | 13.600 mm |
| 3 micrometres | 67 | 13.802 mm | 13.400 mm |
| 5 micrometres | 66 | 13.860 mm | 13.200 mm |
| 10 micrometres | 63 | 13.860 mm | 12.600 mm |

Zero coating is a geometric comparison, not a recommended electrical-steel insulation system.

## Thickness tolerances

Worst-case stack height evaluates every steel/coating/gap thickness at its upper bound. Minimum coating and gap thicknesses are clamped to zero. The default 68-sheet stack spans 13.464–14.280 mm under the entered tolerances. Its upper bound exceeds the 14 mm budget.

Using maximum thicknesses in the count equation yields a conservative 66 sheets. This is a dimensional worst-case calculation, not a statistical capability estimate. The budget itself is treated as exact after subtracting the end allowance; use the minimum available budget if surrounding parts have axial tolerances.

Do not double-count coating if a steel supplier's quoted gauge already includes it. Obtain the bare-steel thickness, coating mass/thickness definition, per-face versus total coating convention, and the thickness under specified measurement pressure.

## Individual parts and exports

- Steel layers are individually selectable; each has a lower and upper coating layer.
- The display spread is an extra visual separation only. It never changes engineering quantities or exported assembled thickness.
- The selected-sheet view helps inspect one lamination's profile. It does not reduce the exported assembly to one sheet.
- Coating visibility is a display setting. Coating remains included in stack calculations and GLB export.
- STEP default assembly contains 204 solids: 68 steel sheets and 136 coatings. Zero-thickness coatings are omitted as solids.
- Browser GLB exports true assembly dimensions in metres. STEP and DXF use millimetres.
- DXF contains an external polyline and circular bore, labelled provisional. Its tessellated tooth tips and non-filleted roots are not production tooling geometry.
- Generated STEP default files are not updated by browser controls. Export the current study JSON and run the documented CAD script to create a changed STEP assembly.

## Measurements needed for a production stack

Get the actual OD, bore, full tooth/slot profile, active steel length, lamination gauge and coating specification. Also determine stack pressure, measured stacking factor, burr height/direction, insulation resistance, grade-specific iron loss at operating electrical frequencies, stack joining and end insulation. Then validate electromagnetic performance, winding insertion, thermal paths and mechanical retention.

Current selection and alternatives: [Packaging choices](PACKAGING-CHOICES.md). Radial winding capacity and magnetic performance remain unverified.

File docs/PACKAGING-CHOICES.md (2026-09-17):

# Packaging decision: provisional Choice C

Status: selected for the current study, not approved for manufacture or rated performance. This supersedes the assumed Ø52 stator bore and long ring sleeve. Manufacturer exterior remains Ø98 × 38.5 mm with the existing mounting interfaces; internal dimensions below are Primeform choices.

## Alternatives considered

| Geometry (mm) | Previous assumption | A | B | C — selected |
|---|---:|---:|---:|---:|
| Stator OD | 80 | 80 | 80 | 80 |
| Stator bore / nominal ring location | 52 | 56 | 58 | 60 |
| Slot-root diameter | 62 | 64 | 66 | 68 |
| Radial stator back iron | 5 | 4 | 4 | 4 |
| Radial tooth region, including tip | 9 | 8 | 7 | 6 |
| Outer-edge material for M2.5 on Ø54 PCD, assuming ring OD equals bore | Not applicable to old flanged design | -0.25 | 0.75 | 1.75 |

Choice C retains useful back iron while accommodating the existing internal ring screw pattern. Choice B preserves more winding space but has only 0.75 mm outside the thread major diameter before fit allowances. Neither figure is a strength qualification. Actual selected ring OD 59.96 mm reduces C's edge material to approximately 1.73 mm.

The 4 mm back iron is a comparison choice, not a magnetic saturation calculation. The 6 mm tooth region is not usable copper area. Slot geometry, insulation, turns, conductor size, copper loss and iron loss must be evaluated together. A/B remain alternatives if C cannot meet winding requirements.

## Selected interfaces

- Stator: Ø80 OD, Ø60 bore, Ø68 slot roots, 36 teeth, 68 sheets with gross length 13.872 mm. Stack centre moves 4.5 mm forward, giving z -2.436 to 11.436 mm.
- Ring: Ø59.96 OD supplies radial location, with 0.020 mm nominal radial bond gap. Compact rim spans z 5.75 to 13.25 mm; gear teeth remain z 5.75 to 10.75 mm. The long sleeve and ring-owned stator shoulder are removed. Gear teeth, gear plane and 9:1 ratio are unchanged.
- Ring attachment: eight existing M2.5 × 6 screws on Ø54 PCD; mounting face remains z 13.25 mm, nominal screw penetration 3.3 mm. Thread capacity, tolerances and torque are not released.
- Housing: an integral annular shoulder at z 11.436 mm, radii 30.1 to 33.5 mm, stops the stator steel at its back-iron region. The annulus extends into the existing housing floor; it does not bridge the rotor swept region.
- Ring-to-stator overlap: z 5.75 to 11.436 mm, only 5.686 mm long. Adhesive is a provisional retention method. This short locating length needs tilt, runout, torque and thermal checks.
- Winding proxy: radii 34.5 to 39 mm, z -3.3 to 12.3 mm. End-turn projection beyond the steel remains 0.864 mm. Radial bundle depth is shortened; no winding capacity is claimed. The main floor at z 13.25 mm gives nominal 0.95 mm axial allowance at that winding envelope; local surface/tolerance checks remain necessary.

The complete ring lies radially within the stator bore. Its front mounting rim extends 1.814 mm beyond the steel stack axially. Full axial containment of every part of the ring is NOT achieved; that would require changing the mounting seat and screw engagement. The toothed band is axially contained by the shifted stack.

## Checks and outstanding issues

Generated ring and housing are each one valid solid. Ring STEP round-trips; gear assembly remains five solids. Nominal ring clearance is checked against source housing, rear housing, output carrier, output bearings, hub, and stator/winding envelopes. The new housing shoulder has zero calculated overlap with the selected stator, winding and ring envelopes. Source housing material is preserved, and external axial extent is unchanged.

This does not validate the full actuator. Rotor/magnets remain at their previous positions: magnet span -7 to 7 mm now overlaps the shifted steel by only 9.436 mm. Rotor axial packaging must be redesigned without sacrificing end-bell or bearing clearances. Existing boss/yoke and end-bell/rear-housing interferences remain. Short bond length, radial fit, winding capacity, structural strength, ring distortion, thermal expansion, housing machining fillets and installation paths remain open.

See `public/data/packaging-choice.json`, `public/design/stator-mount-validation.json` and `public/design/housing-study.json`. Lamination STEP/DXF exports use the selected radial profile; the standalone stack export is at its own local origin, while the assembly viewer applies the 4.5 mm offset.

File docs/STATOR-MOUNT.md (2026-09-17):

# Stator mounting — Choice C

The current model uses a compact ring gear as the stator radial locator and a main-housing shoulder as the axial stop. The previous Ø52 bore, long ring sleeve and ring-owned stator shoulder are superseded.

See [packaging choices and selection](PACKAGING-CHOICES.md) for the alternatives, dimensions, reasons, axial layout and unresolved issues. The selected dimensions are Ø60 stator bore, Ø68 slot root, Ø80 stator OD, Ø59.96 ring OD, and a housing stop at z 11.436 mm. The stator moves 4.5 mm forward. This is a packaging study, not an OEM reconstruction or validated electromagnetic design.

Rebuild with `python cad/build_gears.py`, `python cad/build_housing.py`, `python scripts/build_bom.py`, and `npm run lamination`. The ring and housing generators retain their respective nominal solid and overlap checks. The ring tooth design and 9:1 ratio are unchanged. Rotor alignment and existing rotor/housing clashes remain unresolved.

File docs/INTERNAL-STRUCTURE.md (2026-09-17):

# AK80-9 V3.0 internal structure findings

Reference study R0, checked 2026-09-17. See [source register](SOURCES.md) for links. Facts below distinguish a numerical specification, a CAD object and a marketing illustration; these provide different levels of evidence.

## Motor

S1 specifies 36 stator slots, 21 pole pairs, delta winding, 100 KV, Kt 0.095 Nm/A, 160 mOhm terminal-to-terminal resistance and 116 microhenry terminal-to-terminal inductance. Forty-two magnetic poles follow from 21 pole pairs; this does **not** establish the number of physical magnet segments.

S7 shows an annular outward-tooth wound stator, surrounded by an outer rotor with magnets on its inside circumference. It supports the outer-rotor architecture. The image does not establish steel grade, stack dimensions, magnet arc/thickness, magnetization, winding turns, conductor size or the insulation system.

The source assembly has a parent named rotor, but its leaf geometry comprises the sun/input shaft, two 6701-ZZ bearings, encoder target magnet and a hub. It does not contain a complete electromagnetic rotor. Neither the stator laminations nor coils appear as manufacturing geometry. Do not mistake a named subassembly for a complete parts list.

At the published rated output speed, motor speed is 390 × 9 = 3510 rpm and electrical frequency is 3510 / 60 × 21 = 1228.5 Hz. At the stated no-load speed, those values are 5130 rpm and 1795.5 Hz. These are derived kinematic values, not verified loss-test conditions. Steel selection needs relevant loss data and electromagnetic analysis.

## Gear train

The product specifies 9:1 planetary reduction. The exploded illustration S7 shows three planet gears and a separate annular internal ring. This is recorded as an illustration inference. STEP does not contain the full planet/ring/pin set; a complete gear drawing cannot be recovered from it.

For a conventional simple planetary set with fixed ring, sun input and carrier output, the relation would be `i = 1 + Zr/Zs`. A 9:1 ratio would require `Zr = 8 Zs`; common module and unshifted reference geometry imply `Zp = (Zr - Zs)/2`. These equations do not choose unique tooth counts, establish profile shifts, or prove the exact OEM construction. Verify architecture, tooth counts, pressure angle, face width and clearances before using them to design a replacement.

Material, hardness/case depth, gear precision, planet bearing type, pin retention, lubricant and backlash-setting method remain unresolved. The published backlash is 15 arcmin (0.25 degrees); do not substitute older-generation values.

## Bearings and interfaces recovered from CAD

| Part | CAD qty | Dimension or feature | Limit |
|---|---:|---|---|
| 6701-ZZ | 2 | 12 x 18 x 4 mm nominal bearing size | OEM maker, clearance and grease unknown |
| 6707-ZZ | 1 | 35 x 44 x 5 mm nominal bearing size | Load case, fit and preload unresolved |
| EZO 625-ZZ | 1 | 5 x 16 x 5 mm nominal size | Exact supplier option must be matched |
| Target magnet | 1 | Diameter 6 x 2.5 mm in CAD | Magnet grade and magnetization unknown |
| Output carrier | 1 | Diameter 37 x 7.5 mm CAD bounding envelope | Not a tolerance drawing |
| Main housing | 1 | Diameter 98 x 24.2 mm CAD bounding envelope | Alloy, fits and finish unspecified |
| Rear housing | 1 | Diameter 98 x 9 mm CAD envelope | Same caveat |
| Driver cover | 1 | Diameter 71 x 11 mm CAD envelope | Same caveat |
| M2.5 x 6 countersunk screws | 24 | Explicit STEP product name and occurrences | Strength class and tightening torque unknown |
| M2 x 12 screws | 6 | Explicit STEP product name and occurrences | 14 mm total model length includes head |

S2 gives the V3.0 external envelope diameter 98 x 38.5 +/-0.5 mm, 8 x M3 housing holes on diameter 85 PCD at the indicated faces, and 6 x M4 output holes on diameter 28 PCD. Thread depth and usable engagement are not specified. Diameter 48 and 37 shoulder callouts and a diameter 3 depth-3 locating feature also appear. Consult the complete drawing for orientation; do not mix these interfaces with an older AK80-9 drawing.

The manufacturer's assembly-table dynamic/static ratings (2760/2810 N) do not specify permissible arbitrary joint bending moments and must not be assigned to each bearing individually.

## Driver and harness

S6 pp.7–13 identifies AK60-4820-1C-A2 as compatible with AK80-9. It specifies 48 V nominal, 18–52 V operating range, 20 A RMS rated driver output, 60 A peak driver output, 63 x 57 mm outline, 1 Mbit/s CAN and up to 100 degrees C board temperature. These are driver ratings, not authorization to drive the motor at those currents continuously.

The actuator STEP calls the embedded driver C-AK-DRV-12S_V3.00_L. The separately downloaded current driver STEP still contains AK-DRV-12S_V3.00 labels. Confirm board revision and firmware with the actual unit; names and date listings alone do not prove an identical assembly.

The separate driver file yields **205 electronic reference designators**: 78 capacitors, 73 resistors, 12 transistors, 11 ICs, 18 diode/LED positions, 6 inductors, 3 connectors, and one each of a transformer/coupled device, TVS, oscillator and E-designated unresolved item. Prefixes determine these categories; they are not circuit identifications. Some C-designators use R-package geometry, demonstrating that STEP library labels cannot establish actual parts. See [complete inventory](DRIVER-INVENTORY.md).

The file name says without capacitor while small capacitor designators remain. We cannot establish the bulk/DC-link capacitor assembly, capacitance, voltage, ESR or ripple rating from that label. The schematic/netlist and electronic purchase BOM remain missing.

The manual resolves connector detail beyond the abbreviated product table:

- Power/CAN: AMASS XT30PW(2+2)-M on the board; XT30(2+2)-F cable mate. Pin functions are supply +, supply -, CAN_H and CAN_L in manual order. Verify the connector drawing's viewing direction before wiring.
- UART: CJT A1257WR-S-3P with A1257H-3P cable mate. Functions: GND, RX and TX in manual order.
- Power leads: 16 AWG silicone; CAN leads: 30 AWG PTFE, OD 0.64 mm. Detailed cable length says 100 +/-10 mm, while the remarks also say +/-2 mm. Confirm the harness drawing.
- Serial harness: 30 AWG, OD 0.64 mm, detailed length 200 +/-10 mm. Mate and tolerance still need matching to the actual cable.

## Source discrepancies to resolve

1. **Encoder:** S1 says one 16-bit magnetic encoder. S6 p.4 says 16-bit with up to 21-bit requiring custom firmware; its p.8 table says 21-bit. Do not silently advertise 21-bit for the reference actuator.
2. **Driver:** legacy CAD names/outline differ from current manual/download naming. Keep both sources until the actual board is identified.
3. **Current:** the motor product page labels current ADC; the driver manual explicitly uses RMS and peak current. These are not interchangeable in copper-loss, torque-constant or MOSFET calculations.
4. **Speed:** 100 KV x 48 V / 9 = 533 rpm differs from the listed 570 rpm no-load output. Preserve the published value and obtain test conditions instead of forcing consistency.
5. **Cable dimensions:** length tolerances disagree within the manual; get the harness drawing before ordering.

## Discussion before selecting manufacturing geometry

The highest-value next input is a physical AK80-9 V3.0 reference sample or a dimensioned lamination drawing. Measure stator OD/bore/active length, a cleaned single sheet and the assembled stack under a stated pressure, plus rotor air gap and magnet arc. Confirm coating thickness per face with the steel/coating supplier.

If a sample is unavailable, decide explicitly to design an original Primeform electromagnetic stack against the reference performance targets. In that route the interactive lamination study provides a starting parameterization, but its current dimensions require electromagnetic, thermal and mechanical design before fabrication. Exact OEM reproduction and an independently designed derivative are different deliverables.

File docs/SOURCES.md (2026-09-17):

# Sources and attribution

Checked 2026-09-17. Local downloads and PDF renderings are kept in ignored `tmp/reference/`; they are not republished here as original documents.

| ID | Primary source | Used for |
|---|---|---|
| S1 | [CubeMars AK80-9 V3.0 product page](https://www.cubemars.com/product/ak80-9-v3-0-robotic-actuator.html) | Performance, topology counts, winding, sensor and reference size |
| S2 | [V3.0 interface PDF](https://www.cubemars.com/data/cms/202602/ak80-9-v3-0-robotic-actuator-2d-drawing.pdf) | Current mounting geometry and envelope tolerance |
| S3 | [V3.0 actuator STEP ZIP](https://www.cubemars.com/data/cms/202602/ak80-9-v3-0-robotic-actuator-3d-drawing.zip) | 43 leaf CAD instances, 54 solids, 14 part types, part labels and geometry |
| S4 | [EZO 625ZZ specification](https://www.ezo-brg.co.jp/english/product/spec.php?eid=00545) | Standard 625-ZZ dimensions |
| S5 | [SMB thin-section bearing catalogue](https://www.smbbearings.com/products/thin-section-bearings.html) | Nominal 6701-ZZ and 6707-ZZ dimensions |
| S6 | [AK Series Module Manual V3.2.0](https://www.cubemars.com/data/cms/202602/ak-series-prodcut-manual-v3-2-0-for-ak-3-0-robotic-actuator.pdf) | pp.4, 7–13: encoder caveat, driver, connectors, pin functions, harness |
| S7 | [CubeMars exploded illustration](https://img.cubemars.com/products/AK70_80/images/AK80-9_02.jpg) | Visual inference: outer rotor, wound annular stator, three planets and separate internal ring |
| S8 | [Driver AK60-4820-1C-A2 without capacitor STEP ZIP](https://www.cubemars.com/data/cms/202604/driver-ak60-4820-1c-a2-without-capacitor.zip) | 205 reference designators and package-model labels |

Some links on the manufacturer page resolve incorrectly under `/product/data/`. The working downloads use `/data/` at the domain root. The actuator download listing date is 2026-02-05; the STEP header says 2025-03-05. These are different dates and are recorded separately.

## File integrity

- Source actuator STEP SHA-256: `f569faf5c38c6cc2af5a510b36160a316161feb9cad37f5d136abe22b7f1beaa`.
- Source separate driver STEP SHA-256: `3c6492221216ea4b7d1baa2194fdfcbbe4fb43ec9d795633e4d6ae964f858e0f`.
- The conversion script records source filenames/dates and hashes in generated manifests. Recheck references if a fresh download changes these hashes.

## Authorship boundaries

`public/models/ak80-9-reference.glb` is a tessellated conversion of CubeMars reference CAD. The conversion does not establish Primeform authorship or an open-hardware license for that manufacturer geometry. Source dimensions and names are attributed to CubeMars; colours, translated component labels, inspection offsets and explanatory notes were added for this workbench.

The provisional lamination profile, its parameterization, viewer code, stack calculations and engineering notes are newly authored project work. They are not representations of an inspected OEM lamination. No fabrication or performance validation has been completed. A license for Primeform's own contributions remains to be selected.

Three.js, Vite, CadQuery, Open Cascade and other dependencies retain their own licenses. Their use does not transfer a license to the reference manufacturer design.

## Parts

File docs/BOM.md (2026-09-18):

# AK80-9 V3.0 KV100 engineering BOM

Reference study R0. Counts in the reference CAD cover every one of its 43 leaf instances, not every physical item in a working actuator. Missing quantities remain unknown. Board children are included in E01 and must not be ordered or costed twice. No line is released for procurement.

| ID | Component | Qty | Evidence | Specification | Open items |
|---|---|---:|---|---|---|
| M01 | Main housing | 1 ea | Reference CAD + Primeform modification | CAD envelope: Ø98 x 24.2 mm; Assembly envelope: Ø98 x 38.5 mm; Mounting: 8 x M3 on Ø85 PCD (drawing); Primeform housing R1: Sixteen 5 mm diameter screw supports extended to housing floors; 16 source screw bores preserved. Gold supports can be hidden to compare source geometry.; Known clearance conflict: Extended supports intersect the provisional rotor yoke. Rotor diameter and housing clearance must be reconciled.; Side holes measured from STEP: One pair has diameter 2.1 mm on +Y side; opposite pair has diameter 3.2 mm. Pair centres x = ±6 mm, z = 3.25 mm in viewer coordinates. Functions and thread specifications unconfirmed.; Radial spaces: Clearance and unfilled material between screw bosses; no OEM functional designation established. Do not treat as validated spare volume. | Alloy, heat treatment, wall tolerances, bearing fits, surface finish and ring-gear attachment are unverified. R1 needs rotor-clearance redesign and cutter-access/fillet validation. Side-hole purpose needs OEM confirmation; retain existing holes. |
| M02 | Rear housing | 1 ea | Reference CAD | CAD envelope: Ø98 x 9 mm | Verify locating pilot, concentricity, thermal contact, fastener engagement and finish. |
| M03 | Driver cover | 1 ea | Reference CAD | CAD envelope: Ø71 x 11 mm; OEM drawing code: BJJ02040285 | Material, insulation clearances, sealing and thermal path need definition. |
| M04 | Closure cover | 1 ea | Reference CAD | CAD envelope: Ø14 x 2 mm | Retention method, tolerance and functional purpose require teardown confirmation. |
| G01 | Output carrier | 1 ea | Reference CAD | CAD envelope: Ø37 x 7.5 mm; Output interface: 6 x M4 on Ø28 PCD (drawing) | Pin attachment, torque path, material, fits and fatigue margin need validation. |
| G02 | Sun gear / input shaft | 1 ea | Source journals + provisional toothed section | CAD bounding box: 6.717 x 6.717 x 21.5 mm; Assembly ratio: 9:1 (not a tooth-count specification); Current study solid: One gear-and-shaft solid. Source journals retained; z 3.75 to 11.25 mm replaced by a 20-tooth involute candidate, module 0.3, pressure angle 20 degrees, face width 7.5 mm. Current tip diameter 6.6 mm; original source envelope listed separately.; Representation: Viewer GLB tessellated from the same solid as provisional-sun-gear.step; source blank excluded from combined study.; Primeform matched gear candidate: 20 teeth; module 0.3; pressure angle 20 degrees; zero profile shift; Candidate backlash: 0.020 mm circular per mesh at nominal centres, from 0.010 mm tooth thinning per gear; not a manufacturing tolerance; Root transition: 0.060 mm circular fillets; not a hob/shaper-generated trochoid; Ratio and assembly: 20 / 70 / 160 teeth; ring fixed, sun input, carrier output: exactly 9:1; three planets at 120 degrees; centres 13.5 mm; Release blockers: Cutting process, steel grade, heat treatment, gear quality, tooth-thickness tolerances, strength, fatigue, lubrication and loaded contact checks | Tooth count, module, pressure angle, profile shift, hardness, case depth and spline/shaft fits remain unresolved. Study tooth profile is not a manufacturing design. Verify involute geometry, profile shift, root strength, mating gears and axial fits. |
| G03 | Input shaft hub | 1 ea | Reference CAD | CAD envelope: Ø44.5 x 14.5 mm; Measured form: Body of revolution about the motor axis, z -9.25 to +5.25 mm; six-spoke flange, r 17.145 to 22.25 mm, z -1.75 to +0.25 mm; hub rim r 21.025 to 22.25 mm; annular pocket r 18.975 to 21.025 mm | This is the rotor-side hub that carries both 6701-ZZ bearings and the encoder target magnet coaxially with the sun shaft; it is not a complete electromagnetic rotor and it is not an outboard disc that bolts to a bell. Magnet/yoke integration is absent and no drive feature between the hub and the sun is visible in the source CAD. |
| B01 | 625-ZZ bearing | 1 ea | Reference CAD | Bore x OD x width: 5 x 16 x 5 mm; Shielding: ZZ, two metal shields; CAD OEM code: C0105000059 / EZO | Select clearance, fit, grease and life from actual radial/axial/moment loads. Do not assign actuator load ratings to this bearing. |
| B02 | 6707-ZZ bearing | 1 ea | Reference CAD | Bore x OD x width: 35 x 44 x 5 mm; Shielding: ZZ; CAD OEM code: C0105000031 | OEM supplier, clearance, load ratings, preload and fit are unspecified. |
| B03 | 6701-ZZ bearing | 2 ea | Reference CAD | Bore x OD x width: 12 x 18 x 4 mm; Shielding: ZZ; CAD OEM code: C0105000046 | OEM supplier, clearance, speed rating, bearing fits and grease need selection. |
| F01 | M2.5 x 6 countersunk screw | 24 ea | Reference CAD | Thread / nominal length: M2.5 x 6 mm; Head: Countersunk internal hex; CAD OEM code: C0203000297; Front joint, 8 screws: NAUO7 and NAUO22-28: M01 main housing to compact G05 ring rim, 54 mm PCD; Rear joint, 16 screws: Remaining F01 instances: M02 rear housing to M01 main housing | Verify head standard, torque, locking method, material and thread engagement. CAD count is 24, not a count of interface holes. |
| F02 | M2 x 12 screw | 6 ea | Reference CAD | Thread / under-head length: M2 x 12 mm; CAD overall length: 14 mm; CAD OEM code: C0203000308 | Verify head style/standard, tightening torque, locking and engagement. |
| E01 | Driver board assembly | 1 ea | Reference CAD | CAD board identifier: BZD02010008 / C-AK-DRV-12S_V3.00_L; CAD envelope: 62.282 x 62.479 x 6.850 mm; Control: FOC; servo and MIT modes; Supply reference: 48 V nominal; Current compatible driver: AK60-4820-1C-A2 (manual p.7); Driver input range: 18–52 V; 48 V nominal; Driver rated output current: 20 A RMS (driver rating, not motor continuous rating); Driver maximum output current: 60 A peak (driver rating, duration not given); Driver outline: 63 x 57 mm (manual; different from legacy CAD envelope); CAN bitrate: 1 Mbit/s; Standby consumption: ≤1 W; Driver ambient: −20 to +65 °C; Driver maximum board temperature: 100 °C; Separate driver inventory: 205 reference designators extracted; see driver-inventory.json, values and MPNs unknown | Assembly STEP identifies C-AK-DRV-12S_V3.00_L, while the current manual/download names AK60-4820-1C-A2. Resolve hardware/firmware revision before procurement. Twelve CAD solids describe packaging, not the IC/passive BOM. Peak duration and thermal derating remain unspecified. |
| E02 | Encoder target magnet | 1 ea | Reference CAD | CAD size: Ø6 x 2.5 mm; OEM code: C0103000453 | Magnetization direction, sensor air gap, concentricity and field range must match selected encoder. |
| EM01 | Stator lamination stack | 1 ea | Not in reference CAD | Slot count: 36 (published); OD / ID / active length: Unpublished; Lamination thickness: 0.20 mm proposed starting point; Individual-sheet model: See Lamination lab: provisional profile, coating and thickness tolerance; live study BOM L01–L03; Choice C profile: OD 80 / bore 60 / slot-root diameter 68 mm; radial back iron 4 mm; 6 mm radial tooth region including tip; Mounting in current study: Ring OD 59.96 mm provides radial location; main housing shoulder provides axial stop; Axial location: 68 sheets; gross 13.872 mm; shifted forward 4.5 mm to z -2.436 through 11.436 mm; Retention: Proposed retaining bond to ring over 5.686 mm axial overlap; bond capacity and stack retention unresolved | Requires magnetic geometry, B-H/loss curves, stack factor, burr limit, stack retention and FEA. Quantity is one proposed stack; individual lamination count unknown. |
| EM02 | Three-phase winding | 1 set | Not in reference CAD | Connection: Delta (published); KV target: 100 rpm/V; Terminal-to-terminal resistance: 160 mΩ published; Terminal-to-terminal inductance: 116 µH published; Choice C envelope: Radial 34.5 to 39 mm; axial -3.3 to 12.3 mm; shorter radial bundles are illustrative, not a verified winding fit | Turns, wire diameter, parallel strands, coil pitch, winding diagram, fill factor and test temperature/frequency unknown. Do not treat terminal resistance as phase-branch resistance in delta. |
| EM03 | Rotor shell (machined as part of the rotor) | 1 ea | Not in reference CAD | Machining: Integral with G03: one machined body, not a separate part; Envelope / wall thickness: Shell portion: r 22.25 to 42.4 mm, z -1.75 to 11.25 mm; Integral with the rotor: The magnet-carrying shell is machined as part of the rotor (G03): the manufacturer hub profile plus a six-spoke web and a pocketed magnet rim in ONE connected solid, 5388.4 mm3, O84.8 x 20.5 mm. There is no hub-to-shell joint. See intersection-matrix.json and rotor.json.; Magnet pockets: 42 pockets machined at 85% arc coverage, r 40.5 to 42.4 mm, z 0.25 to 11.5 mm. Magnets seat in them with 0.000 mm3 interference, verified by cad/check_intersections.py.; Superseded geometry: Earlier revisions used a procedural EM03/endbell plus EM03/yoke, then a separate rotor shell. Both are withdrawn: the end bell was a flat annulus with a 46 mm opening that could not receive the measured O44.5 hub, and splitting the shell from the hub invented a joint the manufacturer does not have. | Rotor radial placement is unproven: the magnet band r 40.5 to 42.4 mm does not match the arcuate slots in the source housings (r 41.766 to 43.236 mm). Magnet grade, bonding, retention and balance are unspecified. |
| EM04 | Rotor permanent magnet set | 1 set | Not in reference CAD | Pole pairs: 21 (published); Magnetic poles: 42 (derived); Physical segment count: Unknown; 42 poles does not establish 42 pieces | Arc, thickness, pole coverage, segment count, coating, grade and magnetization are unknown. |
| EM05 | Slot insulation and end insulation | TBD set | Unresolved | Insulation system: Published class C is an assembly claim; component system not specified | Material, thickness, dielectric rating, creepage and quantity require winding design. |
| EM06 | Winding impregnation compound | TBD g | Unresolved | Function: Electrical insulation and winding retention | Chemistry, cured thermal rating, application mass and cure schedule unknown. |
| G04 | Planet gear set | 3 ea | Illustration inference | Reduction target: 9:1; Tooth counts / module / number of planets: Not disclosed; Planet count: Three visible in manufacturer exploded illustration; verify physical assembly; Primeform matched gear candidate: 70 teeth; module 0.3; pressure angle 20 degrees; zero profile shift; Candidate backlash: 0.020 mm circular per mesh at nominal centres, from 0.010 mm tooth thinning per gear; not a manufacturing tolerance; Root transition: 0.060 mm circular fillets; not a hob/shaper-generated trochoid; Ratio and assembly: 20 / 70 / 160 teeth; ring fixed, sun input, carrier output: exactly 9:1; three planets at 120 degrees; centres 13.5 mm; Release blockers: Cutting process, steel grade, heat treatment, gear quality, tooth-thickness tolerances, strength, fatigue, lubrication and loaded contact checks | Three planets are inferred from the exploded illustration; their teeth and dimensions are omitted from STEP. Need tooth count, module, profile shift, face width, material, hardness and fatigue analysis. |
| G05 | Internal ring gear / stator radial locator | 1 ea | Choice C provisional packaging | Reduction target: 9:1; Separate or integral construction: Separate annular ring is shown in exploded illustration; exact mounting unverified; Primeform matched gear candidate: 160 teeth; module 0.3; pressure angle 20 degrees; zero profile shift; Candidate backlash: 0.020 mm circular per mesh at nominal centres, from 0.010 mm tooth thinning per gear; not a manufacturing tolerance; Root transition: 0.060 mm circular fillets; not a hob/shaper-generated trochoid; Ratio and assembly: 20 / 70 / 160 teeth; ring fixed, sun input, carrier output: exactly 9:1; three planets at 120 degrees; centres 13.5 mm; Release blockers: Cutting process, steel grade, heat treatment, gear quality, tooth-thickness tolerances, strength, fatigue, lubrication and loaded contact checks; Housing joint: Eight M2.5 x 6 source screws on 54 mm PCD; ring mounting face z 13.25 mm; Ring body: OD 59.96 mm; toothed band z 5.75 to 10.75 mm, front mounting rim to z 13.25 mm. Long sleeve and stator shoulder removed.; Nominal screw penetration: 3.3 mm; approximately 1.73 mm outer edge material beyond M2.5 major diameter, strength unverified; Radial stator location: Ring OD to 60 mm stator bore; 0.020 mm radial bond gap; overlap z 5.75 to 11.436 mm; Separate axial stop: Main housing annular shoulder at z 11.436 mm; radii 30.1 to 33.5 mm | Ring tooth profile absent; carrier architecture and ring retention unresolved. |
| G06 | Planet pins and retention | TBD set | Not in reference CAD | Diameter / length / number: Unresolved | Pin bending, shear, fit, surface hardness and carrier thickness need load-based sizing. |
| G07 | Planet bearings or bushings | TBD set | Not in reference CAD | Type / size / number: Unresolved | Determine bearing versus bushing architecture, life, lubrication and clearance. |
| E03 | Rotor position encoder | 1 ea | Published function | Technology: Magnetic; Resolution: 16 bit; Encoder count: 1; no output encoder published; Firmware-dependent resolution: Product page: 16 bit; manual p.4: up to 21 bit with custom firmware; p.8 table lists 21 bit | Exact IC, accuracy, latency, interface, position convention and magnet pairing unresolved. Resolution is not accuracy. |
| E04 | Winding temperature sensor | 1 ea | Published function | Published identifier: NTC MF51B 103F3950; Nominal notation: 10 kΩ / B3950; tolerance to be verified | Sensor count is a design allowance; verify package, tolerance, placement and calibration. |
| E05 | Power and CAN connector | 1 ea | Published manual | Description on product page: XT30 2+2; Specification table: XT30PW-M; CAN connector field is blank; Onboard connector: AMASS XT30PW(2+2)-M; Cable mate: AMASS XT30(2+2)-F; Pin functions, manual p.10: 1: supply + (red); 2: supply − (black); 3: CAN_H (white); 4: CAN_L (blue); External cable scope: Supplied mating accessory; excluded from the internal actuator assembly and BOM quantity; External cable / Included pack: One power/CAN cable (published); External cable / Power conductors: 16 AWG silicone, red/black; External cable / CAN conductors: 30 AWG PTFE, white/blue, OD 0.64 mm; External cable / Nominal length: 100 ±10 mm (manual p.12; remarks also say ±2 mm); External cable / Termination: XT30(2+2)-F; opposite end stripped/tinned 3 ±1 mm | Manual resolves the combined connector naming for AK60-4820-1C-A2. Confirm board revision and physical pin orientation before wiring. External cable: Confirm drawing revision and length tolerance; the manual remarks conflict with its detailed length specification. Verify connector orientation and actual current duty. |
| E06 | UART connector | 1 ea | Published function | Published part: A1257WR-S-3P; Product description: CJT 3-pin; Cable mate: CJT A1257H-3P; Pin functions, manual p.10: 1: GND (black); 2: RX (yellow); 3: TX (green); External cable scope: Supplied mating accessory; excluded from the internal actuator assembly and BOM quantity; External cable / Included pack: One serial cable (published); External cable / Conductors: 30 AWG PTFE; OD 0.64 mm; External cable / Nominal length: 200 ±10 mm (manual p.13; remarks also say ±2 mm); External cable / Termination: GH1.25 3-pin to FC 2 x 4 crimp connector, as described in manual | Confirm pitch, mating part, orientation and voltage levels with driver documentation. External cable: Verify actual mating housing, terminal part numbers and conflicting cable length tolerance against supplied harness. |
| E07 | Power stage, gate drive and sensing | TBD set | Unresolved | Architecture requirement: Three-phase inverter, current sensing, protection; Exact electronic BOM: Not public in inspected sources | Need actual phase-current convention, transient bus rating, MOSFET SOA, shunt design, switching losses and thermal analysis. |
| E08 | Control, communications and power supplies | TBD set | Unresolved | Architecture requirement: MCU, CAN transceiver, regulation, decoupling and protection | MCU, encoder IC, CAN IC, regulator, capacitor and passive part numbers/quantities missing. This parent-level BOM is not a PCB placement BOM. |
| E09 | Bulk DC-link capacitor assembly | TBD set | Unresolved | Reference download: Driver STEP is labelled without capacitor; Capacitance / voltage / ESR / ripple rating: Unknown | The driver file still includes small C-designators; the bulk capacitor configuration cannot be established from the filename. Need circuit, mounting, transient and ripple-current requirements. Verify whether included in purchased E01. |
| C01 | Gear lubricant | TBD g | Unresolved | Selection basis: Speed, contact loads, materials and operating temperature | OEM type, fill mass, service interval and compatibility unknown. |
| C02 | Magnet adhesive and retention | TBD set | Unresolved | Selection basis: Peak rotor speed and temperature | Bondline thickness, cure, adhesive mass and overspeed proof required. |
| C03 | Stator retaining and thermal bondline | TBD set | Unresolved | Selection basis: Stator-to-housing and PCBA thermal paths; Proposed bondline: Radii 29.98 to 30.00 mm; z 5.75 to 11.436 mm; length 5.686 mm; Function: Stator retention to ring OD. Axial stop is main housing, not ring. | Bond capacity, cure, tolerances, stack retention and ring distortion unresolved. |
| C04 | Shims, seals, spacers and thread locking | TBD set | Unresolved | Contents: Determine from tolerance stack and teardown | No seal rating is established. Identify every retained item during physical teardown; do not assume this list is exhaustive. |

## Sources

- S1: [CubeMars V3.0 product specification](https://www.cubemars.com/product/ak80-9-v3-0-robotic-actuator.html)
- S2: [CubeMars V3.0 interface drawing](https://www.cubemars.com/data/cms/202602/ak80-9-v3-0-robotic-actuator-2d-drawing.pdf)
- S3: [CubeMars V3.0 STEP assembly](https://www.cubemars.com/data/cms/202602/ak80-9-v3-0-robotic-actuator-3d-drawing.zip)
- S4: [EZO 625ZZ bearing specification](https://www.ezo-brg.co.jp/english/product/spec.php?eid=00545)
- S5: [SMB thin section bearing dimensions](https://www.smbbearings.com/products/thin-section-bearings.html)
- S6: [CubeMars AK V3.2.0 manual, pp. 7–13](https://www.cubemars.com/data/cms/202602/ak-series-prodcut-manual-v3-2-0-for-ak-3-0-robotic-actuator.pdf)
- S7: [CubeMars AK80-9 exploded illustration](https://img.cubemars.com/products/AK70_80/images/AK80-9_02.jpg)
- S8: [CubeMars separate driver STEP](https://www.cubemars.com/data/cms/202604/driver-ak60-4820-1c-a2-without-capacitor.zip)

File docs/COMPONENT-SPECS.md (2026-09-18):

# Component specifications

## M01 — Main housing

Quantity: 1 ea. Evidence: Reference CAD + Primeform modification.

- **CAD envelope:** Ø98 x 24.2 mm
- **Assembly envelope:** Ø98 x 38.5 mm
- **Mounting:** 8 x M3 on Ø85 PCD (drawing)
- **Primeform housing R1:** Sixteen 5 mm diameter screw supports extended to housing floors; 16 source screw bores preserved. Gold supports can be hidden to compare source geometry.
- **Known clearance conflict:** Extended supports intersect the provisional rotor yoke. Rotor diameter and housing clearance must be reconciled.
- **Side holes measured from STEP:** One pair has diameter 2.1 mm on +Y side; opposite pair has diameter 3.2 mm. Pair centres x = ±6 mm, z = 3.25 mm in viewer coordinates. Functions and thread specifications unconfirmed.
- **Radial spaces:** Clearance and unfilled material between screw bosses; no OEM functional designation established. Do not treat as validated spare volume.
- **Material:** OEM grade unspecified; aluminium alloy is a proposed material family only
- **Make/buy:** Proposed: CNC turning + milling; finish and datums to be specified
- **Unresolved:** Alloy, heat treatment, wall tolerances, bearing fits, surface finish and ring-gear attachment are unverified. R1 needs rotor-clearance redesign and cutter-access/fillet validation. Side-hole purpose needs OEM confirmation; retain existing holes.
- **Source references:** S2, S3

## M02 — Rear housing

Quantity: 1 ea. Evidence: Reference CAD.

- **CAD envelope:** Ø98 x 9 mm
- **Material:** OEM grade unspecified
- **Make/buy:** Proposed: CNC turning + milling
- **Unresolved:** Verify locating pilot, concentricity, thermal contact, fastener engagement and finish.
- **Source references:** S3

## M03 — Driver cover

Quantity: 1 ea. Evidence: Reference CAD.

- **CAD envelope:** Ø71 x 11 mm
- **OEM drawing code:** BJJ02040285
- **Material:** OEM grade unspecified
- **Make/buy:** Proposed: CNC machining
- **Unresolved:** Material, insulation clearances, sealing and thermal path need definition.
- **Source references:** S3

## M04 — Closure cover

Quantity: 1 ea. Evidence: Reference CAD.

- **CAD envelope:** Ø14 x 2 mm
- **Material:** OEM grade unspecified
- **Make/buy:** Proposed: turned disc
- **Unresolved:** Retention method, tolerance and functional purpose require teardown confirmation.
- **Source references:** S3

## G01 — Output carrier

Quantity: 1 ea. Evidence: Reference CAD.

- **CAD envelope:** Ø37 x 7.5 mm
- **Output interface:** 6 x M4 on Ø28 PCD (drawing)
- **Material:** OEM grade unspecified
- **Make/buy:** Proposed: machined carrier
- **Unresolved:** Pin attachment, torque path, material, fits and fatigue margin need validation.
- **Source references:** S2, S3

## G02 — Sun gear / input shaft

Quantity: 1 ea. Evidence: Source journals + provisional toothed section.

- **CAD bounding box:** 6.717 x 6.717 x 21.5 mm
- **Assembly ratio:** 9:1 (not a tooth-count specification)
- **Current study solid:** One gear-and-shaft solid. Source journals retained; z 3.75 to 11.25 mm replaced by a 20-tooth involute candidate, module 0.3, pressure angle 20 degrees, face width 7.5 mm. Current tip diameter 6.6 mm; original source envelope listed separately.
- **Representation:** Viewer GLB tessellated from the same solid as provisional-sun-gear.step; source blank excluded from combined study.
- **Primeform matched gear candidate:** 20 teeth; module 0.3; pressure angle 20 degrees; zero profile shift
- **Candidate backlash:** 0.020 mm circular per mesh at nominal centres, from 0.010 mm tooth thinning per gear; not a manufacturing tolerance
- **Root transition:** 0.060 mm circular fillets; not a hob/shaper-generated trochoid
- **Ratio and assembly:** 20 / 70 / 160 teeth; ring fixed, sun input, carrier output: exactly 9:1; three planets at 120 degrees; centres 13.5 mm
- **Release blockers:** Cutting process, steel grade, heat treatment, gear quality, tooth-thickness tolerances, strength, fatigue, lubrication and loaded contact checks
- **Material:** OEM steel and hardness unspecified
- **Make/buy:** Proposed: gear cutting, heat treatment, finish grinding
- **Unresolved:** Tooth count, module, pressure angle, profile shift, hardness, case depth and spline/shaft fits remain unresolved. Study tooth profile is not a manufacturing design. Verify involute geometry, profile shift, root strength, mating gears and axial fits.
- **Source references:** S1, S3

## G03 — Input shaft hub

Quantity: 1 ea. Evidence: Reference CAD.

- **CAD envelope:** Ø44.5 x 14.5 mm
- **Measured form:** Body of revolution about the motor axis, z -9.25 to +5.25 mm; six-spoke flange, r 17.145 to 22.25 mm, z -1.75 to +0.25 mm; hub rim r 21.025 to 22.25 mm; annular pocket r 18.975 to 21.025 mm
- **Material:** OEM material unspecified
- **Make/buy:** Proposed: precision machining
- **Unresolved:** This is the rotor-side hub that carries both 6701-ZZ bearings and the encoder target magnet coaxially with the sun shaft; it is not a complete electromagnetic rotor and it is not an outboard disc that bolts to a bell. Magnet/yoke integration is absent and no drive feature between the hub and the sun is visible in the source CAD.
- **Source references:** S3

## B01 — 625-ZZ bearing

Quantity: 1 ea. Evidence: Reference CAD.

- **Bore x OD x width:** 5 x 16 x 5 mm
- **Shielding:** ZZ, two metal shields
- **CAD OEM code:** C0105000059 / EZO
- **Material:** Verify supplier steel, cage and lubricant
- **Make/buy:** Buy: EZO 625ZZ or qualified equivalent
- **Unresolved:** Select clearance, fit, grease and life from actual radial/axial/moment loads. Do not assign actuator load ratings to this bearing.
- **Source references:** S3, S4

## B02 — 6707-ZZ bearing

Quantity: 1 ea. Evidence: Reference CAD.

- **Bore x OD x width:** 35 x 44 x 5 mm
- **Shielding:** ZZ
- **CAD OEM code:** C0105000031
- **Material:** Verify supplier steel, cage and lubricant
- **Make/buy:** Buy: qualified 6707ZZ
- **Unresolved:** OEM supplier, clearance, load ratings, preload and fit are unspecified.
- **Source references:** S3, S5

## B03 — 6701-ZZ bearing

Quantity: 2 ea. Evidence: Reference CAD.

- **Bore x OD x width:** 12 x 18 x 4 mm
- **Shielding:** ZZ
- **CAD OEM code:** C0105000046
- **Material:** Verify supplier steel, cage and lubricant
- **Make/buy:** Buy: qualified 6701ZZ
- **Unresolved:** OEM supplier, clearance, speed rating, bearing fits and grease need selection.
- **Source references:** S3, S5

## F01 — M2.5 x 6 countersunk screw

Quantity: 24 ea. Evidence: Reference CAD.

- **Thread / nominal length:** M2.5 x 6 mm
- **Head:** Countersunk internal hex
- **CAD OEM code:** C0203000297
- **Front joint, 8 screws:** NAUO7 and NAUO22-28: M01 main housing to compact G05 ring rim, 54 mm PCD
- **Rear joint, 16 screws:** Remaining F01 instances: M02 rear housing to M01 main housing
- **Material:** Strength class / coating unspecified
- **Make/buy:** Buy after fastener specification release
- **Unresolved:** Verify head standard, torque, locking method, material and thread engagement. CAD count is 24, not a count of interface holes.
- **Source references:** S3

## F02 — M2 x 12 screw

Quantity: 6 ea. Evidence: Reference CAD.

- **Thread / under-head length:** M2 x 12 mm
- **CAD overall length:** 14 mm
- **CAD OEM code:** C0203000308
- **Material:** Strength class / coating unspecified
- **Make/buy:** Buy after fastener specification release
- **Unresolved:** Verify head style/standard, tightening torque, locking and engagement.
- **Source references:** S3

## E01 — Driver board assembly

Quantity: 1 ea. Evidence: Reference CAD.

- **CAD board identifier:** BZD02010008 / C-AK-DRV-12S_V3.00_L
- **CAD envelope:** 62.282 x 62.479 x 6.850 mm
- **Control:** FOC; servo and MIT modes
- **Supply reference:** 48 V nominal
- **Current compatible driver:** AK60-4820-1C-A2 (manual p.7)
- **Driver input range:** 18–52 V; 48 V nominal
- **Driver rated output current:** 20 A RMS (driver rating, not motor continuous rating)
- **Driver maximum output current:** 60 A peak (driver rating, duration not given)
- **Driver outline:** 63 x 57 mm (manual; different from legacy CAD envelope)
- **CAN bitrate:** 1 Mbit/s
- **Standby consumption:** ≤1 W
- **Driver ambient:** −20 to +65 °C
- **Driver maximum board temperature:** 100 °C
- **Separate driver inventory:** 205 reference designators extracted; see driver-inventory.json, values and MPNs unknown
- **Material:** PCBA; substrate and copper weight unspecified
- **Make/buy:** Buy a compatible complete driver, or design a new PCBA
- **Unresolved:** Assembly STEP identifies C-AK-DRV-12S_V3.00_L, while the current manual/download names AK60-4820-1C-A2. Resolve hardware/firmware revision before procurement. Twelve CAD solids describe packaging, not the IC/passive BOM. Peak duration and thermal derating remain unspecified.
- **Source references:** S1, S3, S6, S8

## E02 — Encoder target magnet

Quantity: 1 ea. Evidence: Reference CAD.

- **CAD size:** Ø6 x 2.5 mm
- **OEM code:** C0103000453
- **Material:** Magnet grade and magnetization unspecified
- **Make/buy:** Buy after sensor pairing
- **Unresolved:** Magnetization direction, sensor air gap, concentricity and field range must match selected encoder.
- **Source references:** S3

## EM01 — Stator lamination stack

Quantity: 1 ea. Evidence: Not in reference CAD.

- **Slot count:** 36 (published)
- **OD / ID / active length:** Unpublished
- **Lamination thickness:** 0.20 mm proposed starting point
- **Individual-sheet model:** See Lamination lab: provisional profile, coating and thickness tolerance; live study BOM L01–L03
- **Choice C profile:** OD 80 / bore 60 / slot-root diameter 68 mm; radial back iron 4 mm; 6 mm radial tooth region including tip
- **Mounting in current study:** Ring OD 59.96 mm provides radial location; main housing shoulder provides axial stop
- **Axial location:** 68 sheets; gross 13.872 mm; shifted forward 4.5 mm to z -2.436 through 11.436 mm
- **Retention:** Proposed retaining bond to ring over 5.686 mm axial overlap; bond capacity and stack retention unresolved
- **Material:** Proposed: low-loss non-oriented electrical steel; grade unselected
- **Make/buy:** Prototype profile cutting + insulated stack; production stamping after validation
- **Unresolved:** Requires magnetic geometry, B-H/loss curves, stack factor, burr limit, stack retention and FEA. Quantity is one proposed stack; individual lamination count unknown.
- **Source references:** S1

## EM02 — Three-phase winding

Quantity: 1 set. Evidence: Not in reference CAD.

- **Connection:** Delta (published)
- **KV target:** 100 rpm/V
- **Terminal-to-terminal resistance:** 160 mΩ published
- **Terminal-to-terminal inductance:** 116 µH published
- **Choice C envelope:** Radial 34.5 to 39 mm; axial -3.3 to 12.3 mm; shorter radial bundles are illustrative, not a verified winding fit
- **Material:** Enamelled copper; wire grade unselected
- **Make/buy:** Wind, terminate, impregnate and test
- **Unresolved:** Turns, wire diameter, parallel strands, coil pitch, winding diagram, fill factor and test temperature/frequency unknown. Do not treat terminal resistance as phase-branch resistance in delta.
- **Source references:** S1

## EM03 — Rotor shell (machined as part of the rotor)

Quantity: 1 ea. Evidence: Not in reference CAD.

- **Machining:** Integral with G03: one machined body, not a separate part
- **Envelope / wall thickness:** Shell portion: r 22.25 to 42.4 mm, z -1.75 to 11.25 mm
- **Integral with the rotor:** The magnet-carrying shell is machined as part of the rotor (G03): the manufacturer hub profile plus a six-spoke web and a pocketed magnet rim in ONE connected solid, 5388.4 mm3, O84.8 x 20.5 mm. There is no hub-to-shell joint. See intersection-matrix.json and rotor.json.
- **Magnet pockets:** 42 pockets machined at 85% arc coverage, r 40.5 to 42.4 mm, z 0.25 to 11.5 mm. Magnets seat in them with 0.000 mm3 interference, verified by cad/check_intersections.py.
- **Superseded geometry:** Earlier revisions used a procedural EM03/endbell plus EM03/yoke, then a separate rotor shell. Both are withdrawn: the end bell was a flat annulus with a 46 mm opening that could not receive the measured O44.5 hub, and splitting the shell from the hub invented a joint the manufacturer does not have.
- **Material:** Proposed: magnetic steel yoke with separate structural carrier as required
- **Make/buy:** Machine and dynamically balance
- **Unresolved:** Rotor radial placement is unproven: the magnet band r 40.5 to 42.4 mm does not match the arcuate slots in the source housings (r 41.766 to 43.236 mm). Magnet grade, bonding, retention and balance are unspecified.
- **Source references:** Engineering requirement; not an OEM specification

## EM04 — Rotor permanent magnet set

Quantity: 1 set. Evidence: Not in reference CAD.

- **Pole pairs:** 21 (published)
- **Magnetic poles:** 42 (derived)
- **Physical segment count:** Unknown; 42 poles does not establish 42 pieces
- **Material:** Proposed: high-coercivity NdFeB; grade to follow thermal/demagnetization analysis
- **Make/buy:** Buy custom segments; bond and retain
- **Unresolved:** Arc, thickness, pole coverage, segment count, coating, grade and magnetization are unknown.
- **Source references:** S1

## EM05 — Slot insulation and end insulation

Quantity: TBD set. Evidence: Unresolved.

- **Insulation system:** Published class C is an assembly claim; component system not specified
- **Material:** Film / paper / sleeves to match validated winding system
- **Make/buy:** Cut/form and install
- **Unresolved:** Material, thickness, dielectric rating, creepage and quantity require winding design.
- **Source references:** S1

## EM06 — Winding impregnation compound

Quantity: TBD g. Evidence: Unresolved.

- **Function:** Electrical insulation and winding retention
- **Material:** Varnish or resin compatible with winding insulation
- **Make/buy:** Controlled impregnation / cure
- **Unresolved:** Chemistry, cured thermal rating, application mass and cure schedule unknown.
- **Source references:** Engineering requirement; not an OEM specification

## G04 — Planet gear set

Quantity: 3 ea. Evidence: Illustration inference.

- **Reduction target:** 9:1
- **Tooth counts / module / number of planets:** Not disclosed
- **Planet count:** Three visible in manufacturer exploded illustration; verify physical assembly
- **Primeform matched gear candidate:** 70 teeth; module 0.3; pressure angle 20 degrees; zero profile shift
- **Candidate backlash:** 0.020 mm circular per mesh at nominal centres, from 0.010 mm tooth thinning per gear; not a manufacturing tolerance
- **Root transition:** 0.060 mm circular fillets; not a hob/shaper-generated trochoid
- **Ratio and assembly:** 20 / 70 / 160 teeth; ring fixed, sun input, carrier output: exactly 9:1; three planets at 120 degrees; centres 13.5 mm
- **Release blockers:** Cutting process, steel grade, heat treatment, gear quality, tooth-thickness tolerances, strength, fatigue, lubrication and loaded contact checks
- **Material:** Gear steel and heat treatment to be selected
- **Make/buy:** Gear cutting / heat treatment / inspection
- **Unresolved:** Three planets are inferred from the exploded illustration; their teeth and dimensions are omitted from STEP. Need tooth count, module, profile shift, face width, material, hardness and fatigue analysis.
- **Source references:** S1, S3, S7

## G05 — Internal ring gear / stator radial locator

Quantity: 1 ea. Evidence: Choice C provisional packaging.

- **Reduction target:** 9:1
- **Separate or integral construction:** Separate annular ring is shown in exploded illustration; exact mounting unverified
- **Primeform matched gear candidate:** 160 teeth; module 0.3; pressure angle 20 degrees; zero profile shift
- **Candidate backlash:** 0.020 mm circular per mesh at nominal centres, from 0.010 mm tooth thinning per gear; not a manufacturing tolerance
- **Root transition:** 0.060 mm circular fillets; not a hob/shaper-generated trochoid
- **Ratio and assembly:** 20 / 70 / 160 teeth; ring fixed, sun input, carrier output: exactly 9:1; three planets at 120 degrees; centres 13.5 mm
- **Release blockers:** Cutting process, steel grade, heat treatment, gear quality, tooth-thickness tolerances, strength, fatigue, lubrication and loaded contact checks
- **Housing joint:** Eight M2.5 x 6 source screws on 54 mm PCD; ring mounting face z 13.25 mm
- **Ring body:** OD 59.96 mm; toothed band z 5.75 to 10.75 mm, front mounting rim to z 13.25 mm. Long sleeve and stator shoulder removed.
- **Nominal screw penetration:** 3.3 mm; approximately 1.73 mm outer edge material beyond M2.5 major diameter, strength unverified
- **Radial stator location:** Ring OD to 60 mm stator bore; 0.020 mm radial bond gap; overlap z 5.75 to 11.436 mm
- **Separate axial stop:** Main housing annular shoulder at z 11.436 mm; radii 30.1 to 33.5 mm
- **Material:** Material and hardness to be selected
- **Make/buy:** Internal gear machining or validated alternative
- **Unresolved:** Ring tooth profile absent; carrier architecture and ring retention unresolved.
- **Source references:** S1, S3, S7

## G06 — Planet pins and retention

Quantity: TBD set. Evidence: Not in reference CAD.

- **Diameter / length / number:** Unresolved
- **Material:** Hardened pin steel to be selected
- **Make/buy:** Ground pins + retention
- **Unresolved:** Pin bending, shear, fit, surface hardness and carrier thickness need load-based sizing.
- **Source references:** Engineering requirement; not an OEM specification

## G07 — Planet bearings or bushings

Quantity: TBD set. Evidence: Not in reference CAD.

- **Type / size / number:** Unresolved
- **Material:** To be selected
- **Make/buy:** Buy after pin and gear geometry release
- **Unresolved:** Determine bearing versus bushing architecture, life, lubrication and clearance.
- **Source references:** Engineering requirement; not an OEM specification

## E03 — Rotor position encoder

Quantity: 1 ea. Evidence: Published function.

- **Technology:** Magnetic
- **Resolution:** 16 bit
- **Encoder count:** 1; no output encoder published
- **Firmware-dependent resolution:** Product page: 16 bit; manual p.4: up to 21 bit with custom firmware; p.8 table lists 21 bit
- **Material:** IC / sensor module not identified
- **Make/buy:** Part of E01 purchased PCBA or custom board
- **Unresolved:** Exact IC, accuracy, latency, interface, position convention and magnet pairing unresolved. Resolution is not accuracy.
- **Source references:** S1, S6

## E04 — Winding temperature sensor

Quantity: 1 ea. Evidence: Published function.

- **Published identifier:** NTC MF51B 103F3950
- **Nominal notation:** 10 kΩ / B3950; tolerance to be verified
- **Material:** NTC assembly
- **Make/buy:** Buy matched part and embed in winding
- **Unresolved:** Sensor count is a design allowance; verify package, tolerance, placement and calibration.
- **Source references:** S1

## E05 — Power and CAN connector

Quantity: 1 ea. Evidence: Published manual.

- **Description on product page:** XT30 2+2
- **Specification table:** XT30PW-M; CAN connector field is blank
- **Onboard connector:** AMASS XT30PW(2+2)-M
- **Cable mate:** AMASS XT30(2+2)-F
- **Pin functions, manual p.10:** 1: supply + (red); 2: supply − (black); 3: CAN_H (white); 4: CAN_L (blue)
- **External cable scope:** Supplied mating accessory; excluded from the internal actuator assembly and BOM quantity
- **External cable / Included pack:** One power/CAN cable (published)
- **External cable / Power conductors:** 16 AWG silicone, red/black
- **External cable / CAN conductors:** 30 AWG PTFE, white/blue, OD 0.64 mm
- **External cable / Nominal length:** 100 ±10 mm (manual p.12; remarks also say ±2 mm)
- **External cable / Termination:** XT30(2+2)-F; opposite end stripped/tinned 3 ±1 mm
- **Material:** Connector assembly
- **Make/buy:** Buy only after footprint/pinout verification
- **Unresolved:** Manual resolves the combined connector naming for AK60-4820-1C-A2. Confirm board revision and physical pin orientation before wiring. External cable: Confirm drawing revision and length tolerance; the manual remarks conflict with its detailed length specification. Verify connector orientation and actual current duty.
- **Source references:** S1, S6

## E06 — UART connector

Quantity: 1 ea. Evidence: Published function.

- **Published part:** A1257WR-S-3P
- **Product description:** CJT 3-pin
- **Cable mate:** CJT A1257H-3P
- **Pin functions, manual p.10:** 1: GND (black); 2: RX (yellow); 3: TX (green)
- **External cable scope:** Supplied mating accessory; excluded from the internal actuator assembly and BOM quantity
- **External cable / Included pack:** One serial cable (published)
- **External cable / Conductors:** 30 AWG PTFE; OD 0.64 mm
- **External cable / Nominal length:** 200 ±10 mm (manual p.13; remarks also say ±2 mm)
- **External cable / Termination:** GH1.25 3-pin to FC 2 x 4 crimp connector, as described in manual
- **Material:** Connector assembly
- **Make/buy:** Part of E01; verify mating harness
- **Unresolved:** Confirm pitch, mating part, orientation and voltage levels with driver documentation. External cable: Verify actual mating housing, terminal part numbers and conflicting cable length tolerance against supplied harness.
- **Source references:** S1, S6

## E07 — Power stage, gate drive and sensing

Quantity: TBD set. Evidence: Unresolved.

- **Architecture requirement:** Three-phase inverter, current sensing, protection
- **Exact electronic BOM:** Not public in inspected sources
- **Material:** MOSFETs, gate driver, shunts and passives unselected
- **Make/buy:** Included in purchased E01; custom schematic required to make locally
- **Unresolved:** Need actual phase-current convention, transient bus rating, MOSFET SOA, shunt design, switching losses and thermal analysis.
- **Source references:** Engineering requirement; not an OEM specification

## E08 — Control, communications and power supplies

Quantity: TBD set. Evidence: Unresolved.

- **Architecture requirement:** MCU, CAN transceiver, regulation, decoupling and protection
- **Material:** ICs and passives unselected
- **Make/buy:** Included in purchased E01; custom schematic required to make locally
- **Unresolved:** MCU, encoder IC, CAN IC, regulator, capacitor and passive part numbers/quantities missing. This parent-level BOM is not a PCB placement BOM.
- **Source references:** Engineering requirement; not an OEM specification

## E09 — Bulk DC-link capacitor assembly

Quantity: TBD set. Evidence: Unresolved.

- **Reference download:** Driver STEP is labelled without capacitor
- **Capacitance / voltage / ESR / ripple rating:** Unknown
- **Material:** Capacitor technology and specification unselected
- **Make/buy:** Confirm driver configuration before selecting
- **Unresolved:** The driver file still includes small C-designators; the bulk capacitor configuration cannot be established from the filename. Need circuit, mounting, transient and ripple-current requirements. Verify whether included in purchased E01.
- **Source references:** S8

## C01 — Gear lubricant

Quantity: TBD g. Evidence: Unresolved.

- **Selection basis:** Speed, contact loads, materials and operating temperature
- **Material:** Grease grade unselected
- **Make/buy:** Metered fill after compatibility validation
- **Unresolved:** OEM type, fill mass, service interval and compatibility unknown.
- **Source references:** Engineering requirement; not an OEM specification

## C02 — Magnet adhesive and retention

Quantity: TBD set. Evidence: Unresolved.

- **Selection basis:** Peak rotor speed and temperature
- **Material:** Structural adhesive / retention method unselected
- **Make/buy:** Controlled surface preparation, bond and cure
- **Unresolved:** Bondline thickness, cure, adhesive mass and overspeed proof required.
- **Source references:** Engineering requirement; not an OEM specification

## C03 — Stator retaining and thermal bondline

Quantity: TBD set. Evidence: Unresolved.

- **Selection basis:** Stator-to-housing and PCBA thermal paths
- **Proposed bondline:** Radii 29.98 to 30.00 mm; z 5.75 to 11.436 mm; length 5.686 mm
- **Function:** Stator retention to ring OD. Axial stop is main housing, not ring.
- **Material:** Retaining adhesive grade unselected
- **Make/buy:** Controlled application
- **Unresolved:** Bond capacity, cure, tolerances, stack retention and ring distortion unresolved.
- **Source references:** Engineering requirement; not an OEM specification

## C04 — Shims, seals, spacers and thread locking

Quantity: TBD set. Evidence: Unresolved.

- **Contents:** Determine from tolerance stack and teardown
- **Material:** Unselected
- **Make/buy:** Select after assembly tolerancing
- **Unresolved:** No seal rating is established. Identify every retained item during physical teardown; do not assume this list is exhaustive.
- **Source references:** Engineering requirement; not an OEM specification

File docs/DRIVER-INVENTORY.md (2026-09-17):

# Driver component inventory

205 reference designators extracted from [manufacturer driver STEP](https://www.cubemars.com/data/cms/202604/driver-ak60-4820-1c-a2-without-capacitor.zip).

Package models may be generic library placeholders. No netlist, values or IC identities are established.
Source filename says without capacitor; absent bulk/DC-link capacitors must be investigated separately.
All items are children of purchased PCBA E01, not additional items to order with a complete board.

| Ref | Category | CAD occurrences | Package model labels | Value / MPN |
|---|---|---:|---|---|
| C1 | Capacitor | 1 | C_0402-8.step, C_0402.step | Unknown |
| C2 | Capacitor | 1 | R_0402-0.step, R_0402.step | Unknown |
| C3 | Capacitor | 1 | C_0402-8.step, C_0402.step | Unknown |
| C4 | Capacitor | 1 | R_0402-0.step, R_0402.step | Unknown |
| C5 | Capacitor | 1 | C_0603-13.step, C_0603.step | Unknown |
| C6 | Capacitor | 1 | C_0805-11.step, C_0805.step | Unknown |
| C7 | Capacitor | 1 | C_1206-6.step, C_1206.step | Unknown |
| C8 | Capacitor | 1 | C_1206-6.step, C_1206.step | Unknown |
| C9 | Capacitor | 1 | C_1206-6.step, C_1206.step | Unknown |
| C10 | Capacitor | 1 | C_1206-6.step, C_1206.step | Unknown |
| C11 | Capacitor | 1 | C_1206-6.step, C_1206.step | Unknown |
| C14 | Capacitor | 1 | C_1206-6.step, C_1206.step | Unknown |
| C15 | Capacitor | 1 | C_1206-6.step, C_1206.step | Unknown |
| C16 | Capacitor | 1 | C_1206-6.step, C_1206.step | Unknown |
| C17 | Capacitor | 1 | C_1206-6.step, C_1206.step | Unknown |
| C18 | Capacitor | 1 | C_1206-6.step, C_1206.step | Unknown |
| C19 | Capacitor | 1 | C_1206-6.step, C_1206.step | Unknown |
| C20 | Capacitor | 1 | C_1206-6.step, C_1206.step | Unknown |
| C21 | Capacitor | 1 | C_1206-6.step, C_1206.step | Unknown |
| C22 | Capacitor | 1 | C_1206-6.step, C_1206.step | Unknown |
| C23 | Capacitor | 1 | C_1206-6.step, C_1206.step | Unknown |
| C24 | Capacitor | 1 | C_1206-6.step, C_1206.step | Unknown |
| C25 | Capacitor | 1 | C_1206-6.step, C_1206.step | Unknown |
| C26 | Capacitor | 1 | C_1206-6.step, C_1206.step | Unknown |
| C27 | Capacitor | 1 | C_1206-6.step, C_1206.step | Unknown |
| C28 | Capacitor | 1 | C_0402-8.step, C_0402.step | Unknown |
| C29 | Capacitor | 1 | C_0402-8.step, C_0402.step | Unknown |
| C30 | Capacitor | 1 | C_0402-8.step, C_0402.step | Unknown |
| C31 | Capacitor | 1 | C_0402-8.step, C_0402.step | Unknown |
| C32 | Capacitor | 1 | C_0402-8.step, C_0402.step | Unknown |
| C33 | Capacitor | 1 | C_0402-8.step, C_0402.step | Unknown |
| C34 | Capacitor | 1 | C_0402-8.step, C_0402.step | Unknown |
| C35 | Capacitor | 1 | C_0402-8.step, C_0402.step | Unknown |
| C36 | Capacitor | 1 | C_0402-8.step, C_0402.step | Unknown |
| C37 | Capacitor | 1 | C_0402-8.step, C_0402.step | Unknown |
| C38 | Capacitor | 1 | C_0402-8.step, C_0402.step | Unknown |
| C39 | Capacitor | 1 | C_0402-8.step, C_0402.step | Unknown |
| C40 | Capacitor | 1 | C_0402-8.step, C_0402.step | Unknown |
| C41 | Capacitor | 1 | C_0402-8.step, C_0402.step | Unknown |
| C42 | Capacitor | 1 | C_0402-8.step, C_0402.step | Unknown |
| C43 | Capacitor | 1 | C_0402-8.step, C_0402.step | Unknown |
| C44 | Capacitor | 1 | C_0805-11.step, C_0805.step | Unknown |
| C45 | Capacitor | 1 | C_0805-11.step, C_0805.step | Unknown |
| C46 | Capacitor | 1 | C_0603-13.step, C_0603.step | Unknown |
| C47 | Capacitor | 1 | C_0603-13.step, C_0603.step | Unknown |
| C48 | Capacitor | 1 | C_0805-11.step, C_0805.step | Unknown |
| C49 | Capacitor | 1 | C_0603-13.step, C_0603.step | Unknown |
| C50 | Capacitor | 1 | C_0603-13.step, C_0603.step | Unknown |
| C51 | Capacitor | 1 | C_0805-11.step, C_0805.step | Unknown |
| C52 | Capacitor | 1 | C_1206-6.step, C_1206.step | Unknown |
| C53 | Capacitor | 1 | C_0805-11.step, C_0805.step | Unknown |
| C54 | Capacitor | 1 | C_0603-13.step, C_0603.step | Unknown |
| C55 | Capacitor | 1 | C_0402-8.step, C_0402.step | Unknown |
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

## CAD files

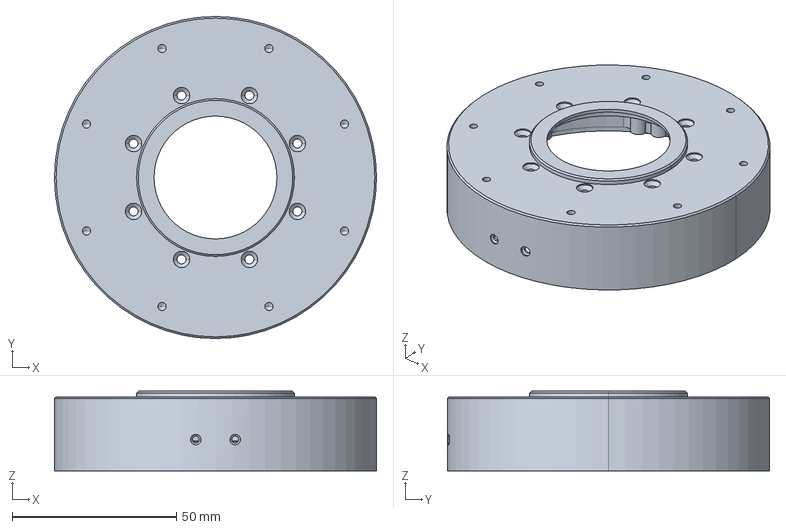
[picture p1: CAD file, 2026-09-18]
public/design/main-housing-supported.step
98.0 x 98.0 x 24.2 mm

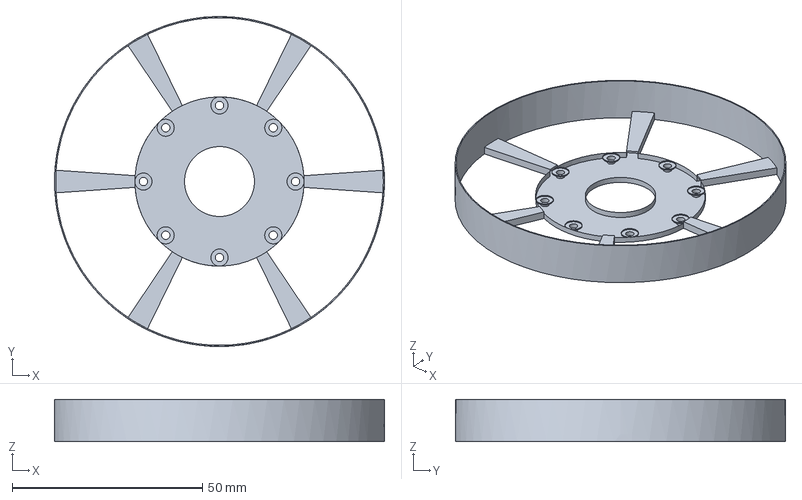
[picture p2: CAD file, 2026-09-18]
public/design/rotor-shell.step
86.8 x 86.8 x 11.2 mm

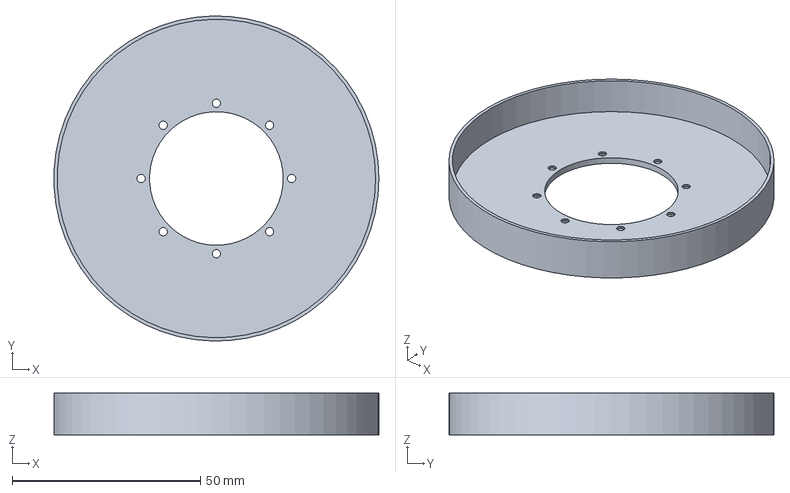
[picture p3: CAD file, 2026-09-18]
public/design/rotor-flange.step
86.3 x 86.4 x 11.2 mm

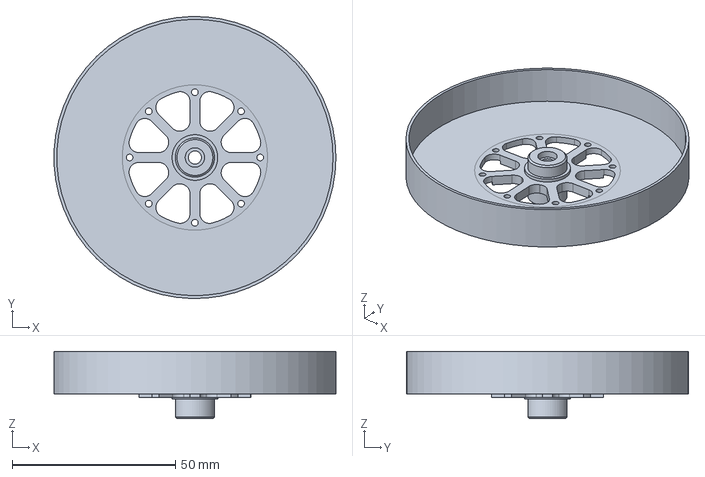
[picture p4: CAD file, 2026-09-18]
public/design/rotor.step
86.3 x 86.4 x 20.7 mm

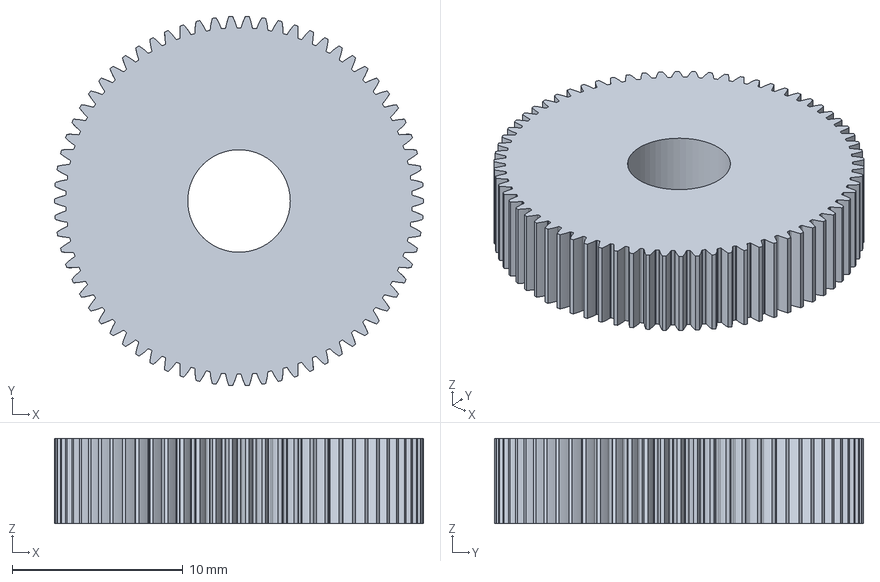
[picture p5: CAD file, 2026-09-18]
public/design/provisional-planet-gear.step
21.6 x 21.6 x 5.00 mm

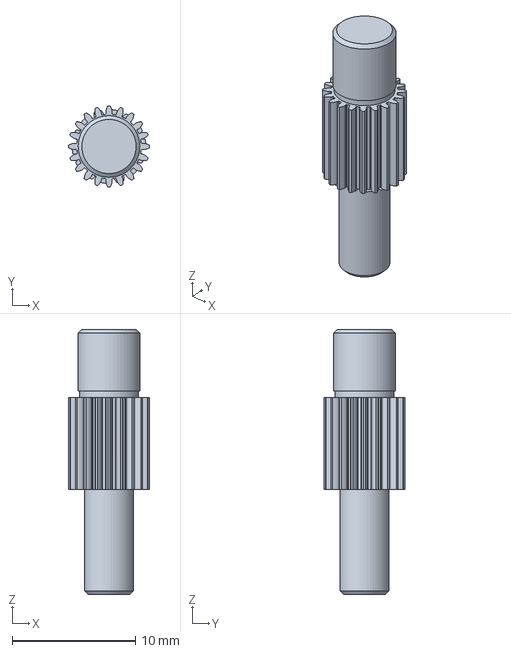
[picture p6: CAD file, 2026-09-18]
public/design/provisional-sun-gear.step
6.60 x 6.60 x 21.5 mm

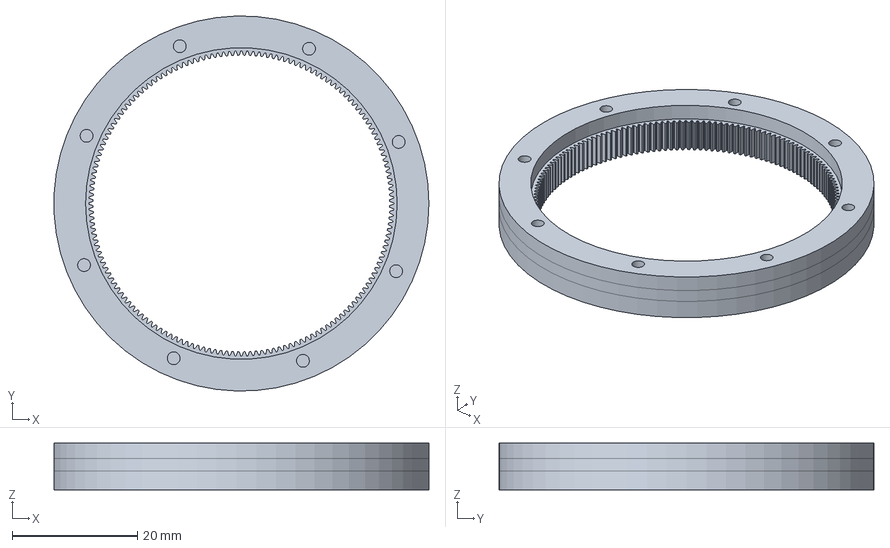
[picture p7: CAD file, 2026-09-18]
public/design/provisional-ring-gear.step
59.9 x 59.9 x 7.50 mm

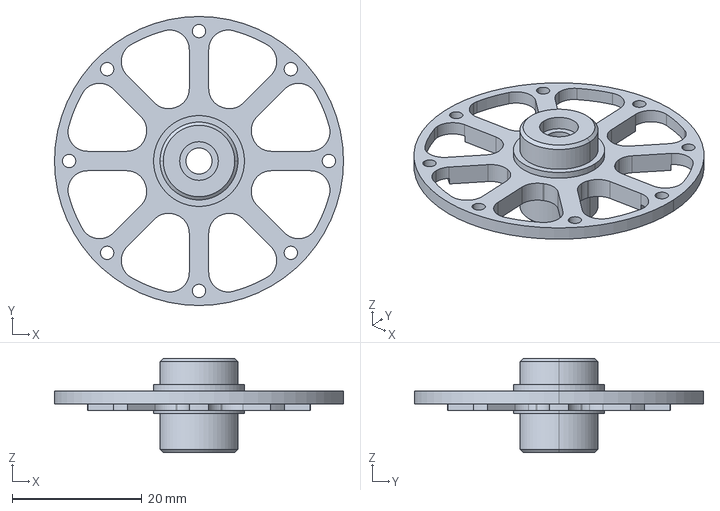
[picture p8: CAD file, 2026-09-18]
public/design/oem-rotor-hub.step
44.5 x 44.5 x 14.5 mm

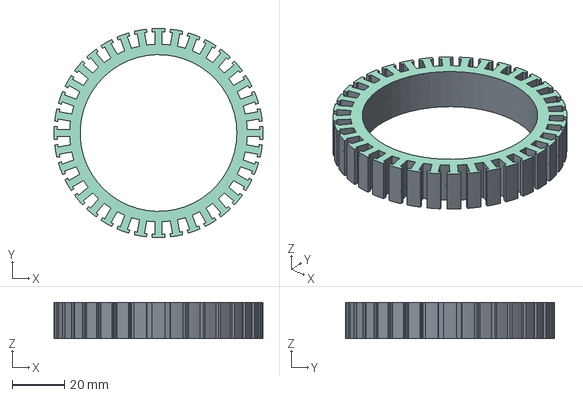
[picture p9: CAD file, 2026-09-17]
public/design/provisional-lamination-stack.step
80.0 x 80.0 x 13.9 mm
L001_steel x 68
L001_coating_lower x 136

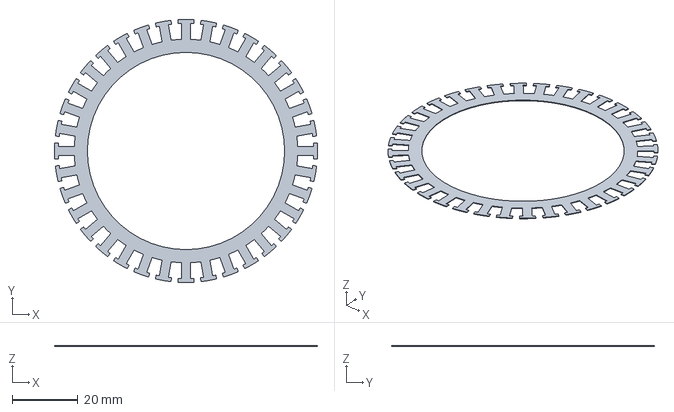
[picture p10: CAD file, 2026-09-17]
public/design/provisional-single-lamination.step
80.0 x 80.0 x 0.2 mm

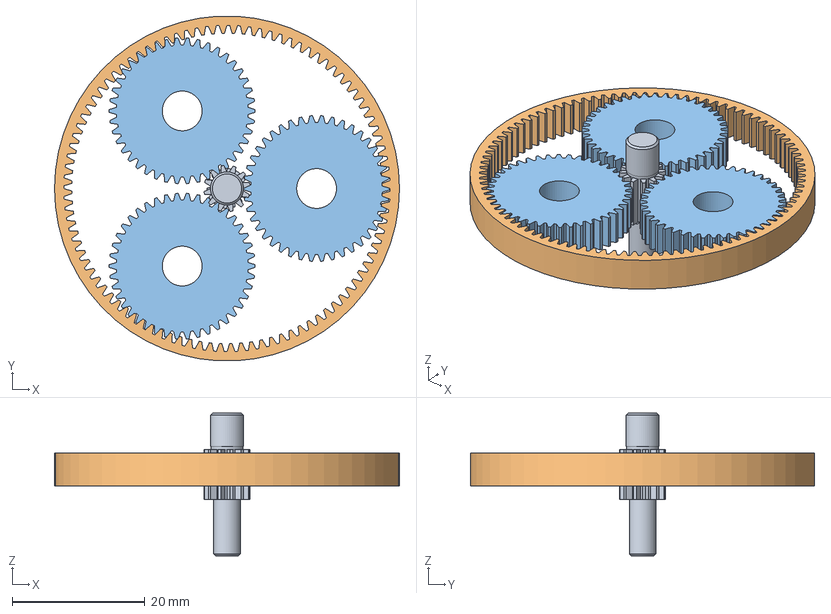
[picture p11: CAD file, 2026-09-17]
public/design/provisional-gear-train.step
52.0 x 51.9 x 21.5 mm
Sun_gear
Ring_gear
Planet_gear_1
Planet_gear_2
Planet_gear_3

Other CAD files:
public/design/provisional-lamination-mm.dxf

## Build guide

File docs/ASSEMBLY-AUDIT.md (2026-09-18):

# Assembly process audit — all 20 steps

Prepared 2026-09-17. Current status after the layout and rotor-shell corrections. Reproduce with:

```powershell
npm test                       # runs the geometry checks first, then the unit tests
npm run test:geometry          # intersections, contacts, hub joint, ring clamp
python cad/check_intersections.py   # pairwise matrix for every modelled body
python cad/check_assembly_contacts.py   # joint contact / gap, all claimed joints
python cad/check_ring_clamp.py          # the eight front screws vs the ring
node tmp/qa/audit-all-steps.mjs         # rendered state of every step
```

Rendered screenshots: `tmp/qa/steps/step-NN.png`.
Machine-readable findings: `public/design/intersection-matrix.json`,
`public/design/assembly-contact-validation.json`.

Step numbers below are the ones shown in the app (`step 1` … `step 20`). The
`A01`-style ids are the internal names for the same rows.

## Interpenetration is now a test, not an inspection

The project had no intersection test. Every geometry regression so far — a hub with no
attachment, a solid ring of 43,791 mm³, magnets cutting 137.7 mm³ into the shell — was
a body passing through another body, and no test caught any of it.

`cad/check_intersections.py` now tests **every pair of modelled bodies** (1,225 pairs
across 50 bodies) in the assembled state and reports two things separately:

- **interpenetration**: the volume of the boolean intersection
- **intended contact**: whether a claimed joint actually touches

It runs as the first step of `npm test`, so `npm test` fails if a body passes through
another. Current result:

| Check | Result |
|---|---|
| Bodies tested | 50 |
| Pairs tested | 1,225 |
| Interpenetrating pairs | **2, both intended fits** |
| Unintended interpenetration | **0** |
| Magnet clashes | **0** (was 42 pairs at 137.7 mm³ each) |
| Intended contacts present | **6 of 6** |

The two remaining overlaps are the fits that are supposed to interfere: hub ∩ sun =
0.324 mm³ (the measured pilot fit) and the housing joint faces at 0.000 mm³.

## The magnet defect that test found

The magnets were cutting **137.7 mm³ into the shell, 42 times over** — visible in the
render as segments buried in the rim. Two causes:

1. the magnets' outer radius (42.5 mm) exceeded the shell's bore band outer face
   (42.4 mm)
2. the spoked web and the magnet band shared the same axial band (web z 0.25…2.25,
   magnets z −2.5…11.5), so every spoke passed through every magnet

The web could not simply move: the hub is only r 22.25 over z −1.75…0.25 and r 6…7
elsewhere, so the web has to sit on the hub's Ø44.5 flange. The shell is now built the
way a real rotor shell is: **the rim is pocketed** — 42 pockets machined to the same
angular width as the segments — and the segments seat in them with zero interference.

| | Before | After |
|---|---|---|
| Shell material | 43,791 mm³ (solid ring) | **2,274 mm³ (pocketed, spoked)** |
| Shell bodies | 2 (invented joint) | **1 connected, valid solid** |
| Magnet interference | 42 pairs × 137.7 mm³ | **0** |
| Shell vs both housings and the hub | clashing | **0.000 mm³** |

## The correction that removed the defects

Two corrections were needed.

**First, the direction of the axial move.** An earlier revision moved the stator,
winding, ring mounting flange and housing seat 4.5 mm rearward. That moved
manufacturer hardware and broke two things:

- the eight front screws stayed at their fixed positions, so the ring clamp was
  destroyed (engagement measured **0.0000 mm³**)
- the ring flange is generated from `ring_z` while the ring teeth live in the gear
  GLB at the gear plane, so the flange and its teeth separated by **2.000 mm**

Moving the ring instead is not an option: it would leave only **0.500 mm** of axial
overlap with the planets where a full 5.000 mm face is needed.

**The fix reverses the direction.** The ring, stator, winding, housing seat and
gear train stay where the manufacturer put them, and the study's own invented rotor
shell moves forward 4.5 mm to meet the stator. Only invented geometry moves.

**Second, the rotor shell was split into two parts when the manufacturer makes it as
one.** The real part is a single spoked shell whose outer rim carries the magnets,
with the sun force-fitted into it. The study had modelled a separate disc plus a
separate rim, which invented a joint that does not exist and produced a 7.75 mm
thick solid ring of 43,791 mm³ — a solid-of-revolution shortcut, not a design.
The shell is now **one connected solid** of **7,482 mm³**: a six-spoke web on the
hub's Ø44.5 front face, an outer rim carrying the magnets on its Ø81 bore, and a
closing flange at the rear.

| Check | Before | After |
|---|---|---|
| Ring clamp (step 3) | 0.0000 mm³, **not clamped** | **8/8 screws engaged, 10.89 mm³** |
| Ring flange vs its teeth (step 2) | 2.000 mm short | overlaps the toothed band |
| Stator front face vs seat (step 4) | — | **contact at z 11.436 = 11.436** |
| Stator/magnet axial overlap | 13.872 mm | **13.872 mm of 13.872 (full)** |
| Rotor shell parts | 2 solids (invented joint) | **1 connected, valid solid** |
| Rotor shell material | 43,791 mm³ (solid ring) | **7,482 mm³ (spoked)** |
| Rotor shell vs rear housing | 194.333 mm³ clash | **0.000 mm³** |
| Rotor shell vs main housing / hub | 0.000 mm³ | **0.000 mm³** |
| Gear face overlap | 5.000 mm | **5.000 mm (full)** |

## The rotor is ONE machined body

The decisive evidence was the manufacturer photograph: the shell's web flows straight
into the central hub boss, and the sun is pressed into it. The hub and the shell are
**one machined part**, not two parts to be joined.

Everything before this had modelled them separately and then argued about how to join
them — which invented a joint the manufacturer does not have, and produced the whole
A06 blocker. `cad/build_rotor.py` now takes the **measured OEM hub** as the starting
point and machines the shell onto it as **one connected solid**:

| | Value |
|---|---|
| Bodies | **1** connected, valid solid |
| Volume | 5,388 mm³ |
| Envelope | Ø84.8 × 20.5 mm, z −9.25 … +11.25 |
| Hub portion | measured OEM NAUO45: six-spoke flange r 17.145…22.25, Ø6 / Ø12 / Ø5.95 bores |
| Shell portion | six-spoke web out of the hub flange; rim r 40.5…42.4 with 42 magnet pockets |
| Sun fit | measured 0.324 mm³ pilot contact, z 3.75…5.25 |
| Unintended interference | **0.000 mm³** against both housings |

**Blocked steps: none.** A06 was "hub retention — not defined"; it is now
"press the sun into the rotor", a real operation. A07 is "install the rotor over the
stator". Both remain `Proposed / requires validation` because fit classes, torque
capacity, press tooling and the insertion path are not defined — but they are no
longer structurally impossible.

## Dimensioned diagrams

Selecting any part in the tree shows a dimensioned axial section in the inspector,
generated from the mesh actually on screen (`src/part-diagram.js`). Every number is
measured from the displayed geometry, so a diagram cannot disagree with the model it
describes. Measured examples:

| Part | Axial | Max Ø | Bores |
|---|---|---|---|
| Rotor, one piece (G03) | 20.5 mm | Ø84.8 | Ø44.5, Ø34.3, Ø12 |
| Ring (G05) | 7.5 mm | Ø59.96 | Ø49.8, Ø47.45, Ø47.4 |
| Main housing (M01) | 24.2 mm | Ø98 | Ø95, Ø94.56, Ø93.78 |

## Where it stands

**No step is blocked. All 20 are geometrically consistent. Eight carry open
engineering items that are not geometric.**

| # | Step(s) | Status | Issue |
|---|---|---|---|
| 1 | step 6 | open | Sun-to-rotor press: fit class, retention, press tooling and torque capacity undefined |
| 2 | step 7 | open | Rotor insertion over the stator: 0.5 mm nominal air gap, path and lead-in not defined |
| 3 | step 11 | open | Both output bearings float: 6707-ZZ and 625-ZZ each 0.0000 mm³ against both claimed receivers |
| 4 | steps 9, 10 | open | Planet pin retention, pin bores and bearing/bushing selection undefined |
| 5 | step 13 | open | Lubricant and seal are placeholders: no groove, shim, preload or quantity |
| 6 | step 15 | open | Sixteen screw thread engagement and tightening torque unspecified |
| 7 | step 17 | open | 205 electronic designators are inventory records only; board positions unmapped |
| 8 | steps 19, 20 | open | Six screw thread engagement; output closure seal and preload undefined |

Steps 1, 2, 3, 4, 5, 8, 12, 14, 16 and 18 are internally consistent and measured.

## The joint that used to block, and why it no longer exists

A06 used to hinge on **how the magnet-carrying shell attaches to the hub**. The
measured answer was 0.000000 mm³ interference at 0.000000 mm distance: coincident
faces with no fit, key, screw or bond, so the rotor torque path was undefined.

That question is now dissolved rather than answered. The manufacturer photograph
shows the shell's web flowing straight into the central hub boss, with the sun
pressed into it: **the hub and the shell are one machined part.** Modelling them as
two bodies and then trying to join them invented a joint that does not exist.

`cad/build_rotor.py` takes the measured OEM hub and machines the shell onto it as one
connected solid, so there is nothing to join. A06 becomes a real operation — press the
sun into the rotor — and the fit it relies on is the measured 0.324 mm³ pilot contact
on the Ø5.95 counterbore.

## Step-by-step table

**vis/total** = meshes visible in that step / total in the model. "stray" = visible
meshes that are neither this step's parts nor its target — the retained
earlier-installed parts, which is intended.

| App step | parts (vis/total) | target (vis/total) | verdict |
|---|---|---|---|
| 1 | M01 2/2 | — | OK; fixture step |
| 2 | G05 1/1 | M01 2/2 | OK; flange now overlaps its toothed band |
| 3 | 8 × F01 1/1 each | M01 2/2, G05 1/1 | **OK; 8/8 engaged, 10.89 mm³** |
| 4 | EM01 204/204, EM05 36/36, EM02 36/36, E04, EM06, C03 | G05 1/1, M01 2/2 | OK; seat contact exact |
| 5 | EM04 42/42, C02 1/1 | EM03/web 1/1, EM03/rim 1/1 | OK geometry; carrier retention open |
| 6 | G03 2/2 | EM03/web 1/1 | **blocked**: carrier-to-hub joint undefined |
| 7 | EM03/web, EM03/rim, EM04 42/42, C02, G03 | M01 2/2, EM01 204/204 | **blocked** by step 6 |
| 8 | B03 2/2, G02 1/1 | G03 2/2, M02 1/1 | OK; hub ∩ sun 0.3241 mm³, bearings 0.0000 mm³ |
| 9 | G06 3/3 | G01 1/1 | pin retention undefined |
| 10 | G07 3/3, G04 3/3 | G06 3/3, G01 1/1 | bearing selection unresolved |
| 11 | B01 1/1, B02 1/1 | M01 2/2, G01 1/1 | **open**: both bearings float |
| 12 | G01, G06, G07, G04 | B01, B02, G02, G05 | insertion path unvalidated |
| 13 | C01 1/1, C04 1/1 | G02, G04, G05, M01 | placeholders only |
| 14 | M02 1/1 | M01 2/2, EM03 2/2, B03 2/2 | **unblocked**: 0.000 mm³ clash on all sides |
| 15 | 16 × F01 1/1 | M02, M01 | **unblocked**; torque unspecified |
| 16 | E02 1/1 | G03 2/2 | OK contact; retention undefined |
| 17 | E01 11/11, E03, E05, E06, E07 6/6, E08, E09 | M02, E02, EM02 36/36, E04 | positions unmapped |
| 18 | M03 1/1 | M02 1/1, E01 11/11 | clearance unverified |
| 19 | F02 6/6 | M03 1/1, M02 1/1 | torque unspecified |
| 20 | M04 1/1 | G01 1/1 | seal/preload undefined |

## Measurements that are sound

- Gear train: 20/70/160 teeth, module 0.3. Sun pitch r 3.0 + planet r 10.5 = 13.500 =
  declared centre distance; ring pitch r 24.0 − planet r 10.5 = 13.500. Face bands
  co-planar at z 8.25 with the full 5.000 mm overlap.
- Stator seat: stator front face z 11.436 = housing seat z 11.436.
- Hub: Ø44.5 × 14.5 mm revolution body, six-spoke flange r 17.145…22.25 at
  z −1.75…+0.25; carries both 6701-ZZ bearings and the encoder magnet at
  0.0000 mm³ interference.
- Hub ∩ sun = 0.3241 mm³ confined to z 3.750…5.250, with a keyed/flat feature
  (0.2022 mm azimuthal spread) on the sun journal.
- Rotor shell (web r 22.25…40.5 z −2.5…+5.25; rim r 40.5…42.4 z +5.25…+11.5):
  0.000 mm³ against both housings and the hub.
- M01 ∩ M02 = 0.000 mm³.

## Figures retired in this audit

- **"Rotor end bell vs NAUO4 = 2666.283 mm³"** referred to the deleted procedural
  `EM03/endbell`. It reproduces exactly against that deleted geometry, so the number
  was real but the part no longer exists. Removed from step 14.
- **"M02 overlaps M01 by 2666.283256 mm³"** (from the handoff) does not hold for the
  source solids: measured **M02 ∩ M01 = 0.000 mm³**. The same number had been
  attached to two different claims.
- **"Extended supports intersect the provisional yoke by 1134.581 mm³"** is still
  reported by `build_housing.py`, but the support bosses are at r 27 ± 2.5 mm while
  the yoke was at r 42.5…45.5 mm, so the two cannot overlap. This figure needs
  re-deriving or retiring.

## Known limits

Contact and clash are measured. Fit classes, torque capacity, preload, insertion
paths, tool access and electrical routing are not. "No clash" in this document means
no interpenetration in the modelled state — it does not mean the joint is designed.

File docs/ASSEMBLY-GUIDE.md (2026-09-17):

# Assembly process

Open **3D assembly → Assembly process**. The process has 20 proposed stages starting with main housing M01, ring/support G05, eight front screws, and the complete prepared stator located radially by G05 and stopped axially by the M01 shoulder. Separate rotor and carrier preparation stages identify work performed outside the actuator. Each stage explicitly names the fitted parts, receiving parts, mating surfaces and joining method.

Previous/Next navigate assembly stages. Before fitting hides the incoming group; Proposed seated state shows it at its modeled destination. Play stages alternates these states and proceeds through the proposal, pausing before known interference steps. This is state-based playback, not a validated insertion animation: no geometry is translated through another part. A user may inspect the proposed seated state of a blocked step without implying it is physically achievable.

Parts are opaque, with normal depth writes. Each physical part instance has a stable distinct color across all stages; multiple meshes belonging to the main housing share its color. Inspector swatches identify the corresponding part colors. Incoming and receiving roles are listed explicitly instead of recoloring all parts by role.

Earlier installed parts always remain visible during actuator installation. Bench preparation shows its local rotor or carrier participants until that subassembly is installed. Future parts stay hidden except explicit receiving-part references needed to explain unresolved connections, such as rear housing bearing-seat ownership in step 8.

Section cuts and the earlier-parts toggle are removed from Assembly process. All process geometry is unclipped; the ordinary viewer's Section control is hidden while the process is active and restored on exit. Nominal seat annotation remains optional and is not a persistent CAD face selection. Fit step frames the visible assembly and the incoming parts. The inspector retains component links and complete mating/process details.

## Open mechanical work

The interface does not resolve physical design problems. Yoke/boss and end-bell/rear-housing clashes remain. Stator insertion onto the integral support, shaft/hub torque transfer, bearing seats and fits, carrier pin retention, PCB mounting and sealing still require definition. Choice C shifts the stator forward 4.5 mm; rotor realignment is not implemented. See PACKAGING-CHOICES.md. A valid insertion animation requires a defined moving subassembly, assembly state, final fit, swept clearance and tool access for that operation.

The earlier generic axial translation was removed because it did not represent assembly. Adhesive, resin and lubricant are process representations, not independently translated solids. Step order remains proposed; advancing past a blocker does not establish successful physical completion.

The downloadable register is `public/data/assembly-sequence.json`. It covers all 35 BOM records, with eight front and sixteen rear F01 screws treated separately. No OEM assembly procedure or manufacturing release is claimed.

Validation: `npm run test:assembly` checks the 20 stages, housing-first order, front screw count, before/after visibility, persistent earlier-part context, stable distinct colors, opaque rendering, no clipping, static transforms, blocking behavior, BOM references, exit restoration and mobile layout. `npm test`, `npm run test:browser`, and `npm run build` check the existing application. These checks do not certify mechanical feasibility.

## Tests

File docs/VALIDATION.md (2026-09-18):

# Validation record

## Reference geometry

- Imported the CubeMars STEP as an assembly and retained 43 unique leaf occurrence IDs.
- Reconciled all 43 occurrences to the 14 CAD-backed BOM rows.
- Counted 54 source solids, including 12 simplified solids inside the driver assembly.
- Measured a centred 98 x 98 x 38.5 mm bounding envelope and converted to metre-unit GLB.
- Parsed the exported GLB and checked for a mesh node for every source occurrence.

## Lamination geometry and calculations

- Default single-sheet solid validates in Open Cascade through CadQuery.
- Default STEP assembly contains 68 steel and 136 coating solids, 204 total.
- Axial stack height is 13.872 mm; single-sheet steel volume is approximately 377.700 mm3 for the provisional profile.
- Unit tests exercise two-sided coatings, N-1 gaps, end allowance, rounding at whole-sheet boundaries, fixed counts, worst-case tolerances, invalid inputs and monotonic layer counts as coating increases.
- Browser GLB export is checked for 204 individually named mesh nodes from the default assembly even when selected-sheet view and display spread are active.

## Browser and build checks

Automated Chromium/Edge checks exercise reference loading, selection/isolation, assembled/exploded/section modes, BOM search, lamination parameter updates, invalid-entry handling, JSON and GLB downloads, and desktop/mobile horizontal layout. Screenshots are inspected for the default stack, spread stack and actuator assembly.

`npm run build` creates a static bundle. The source uses relative asset paths for a subdirectory webview.

## Rotor hub joint audit

- `cad/check_hub_joint.py` asserts the manifest hash of the manufacturer STEP, then measures the input-shaft hub `NAUO45` and its neighbours. Results in `public/design/hub-joint-validation.json`, findings in [rotor hub joint audit](ROTOR-HUB-JOINT.md).
- Measured: the OEM hub is a body of revolution, Ø44.5 x 14.5 mm, with a 2 mm thick six-spoke flange at z -1.75 to +0.25 mm; it is coaxial with the sun shaft and carries both 6701-ZZ bearings and the encoder target magnet with zero interpenetration.
- Measured: the procedural `EM03/endbell` (46 mm opening, z -8.6 to -7.6 mm) does not touch the hub flange and has no surface that can receive it. Assembly step A06 was therefore an unsupported "attach" claim; it is now a blocked step with measured evidence.
- This is a measurement check. No fit, retention, torque capacity, runout or assembly process is qualified by it.

## Not validated

No physical dimensions were measured on hardware. No rotor/stator electromagnetic simulation, winding design, gear stress calculation, tolerance-stack release, bearing-life calculation, collision clearance of omitted internals, driver circuit verification, thermal test, load test or manufacturing release is implied. Visual clipping is uncapped; explosion offsets are inspection annotations, not a disassembly sequence.

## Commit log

2026-09-17 Introduce Primeform Robotics public actuator development
2026-09-17 Add AK80-9 reference workbench and individual lamination study
    [provisional-lamination-mm.dxf, provisional-lamination-stack.step, provisional-single-lamination.step]
2026-09-17 Add full BOM assembly tree and illustrative motor and gear internals
2026-09-17 Keep external cable information under connectors and remove harness geometry
2026-09-17 Extend housing screw supports to floor and document rotor clearance conflict
    [main-housing-supported.step]
2026-09-17 Treat complete gears as tree items instead of individual ring teeth
2026-09-17 Model each gear as one solid with integral teeth in STEP and viewer
    [provisional-gear-train.step, provisional-planet-gear.step, provisional-ring-gear.step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]
2026-09-17 Replace overlapping sun geometry with one STEP-derived gear and shaft solid
    [provisional-gear-train.step, provisional-planet-gear.step, provisional-ring-gear.step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]
2026-09-17 Replace placeholder teeth with matched involute 9:1 candidate and mesh validation
    [provisional-planet-gear.step, provisional-ring-gear.step, provisional-sun-gear.step]
2026-09-17 Add fixed ring mounting flange and integral stator support with fit checks
    [provisional-planet-gear.step, provisional-ring-gear.step, provisional-sun-gear.step]
2026-09-17 Measure and flag rear housing rotor end bell interference
2026-09-17 Add assembly animation and complete proposed mating register
2026-09-17 Withdraw invalid assembly motion and document per-joint path blockers
2026-09-17 Present opaque assembly process with ordered stages and fitting states
2026-09-17 Keep distinct part colors and complete unsectioned assembly context
2026-09-17 Preserve camera across assembly process stages
2026-09-17 Select and document Choice C stator packaging with housing axial stop
    [main-housing-supported.step, provisional-lamination-mm.dxf, provisional-lamination-stack.step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]
2026-09-18 Measure the rotor hub joint and withdraw the unsupported A06 attachment
    The handoff reported that assembly step A06 attached the input shaft hub to a
    rotor end bell with no modelled connection. Measuring the manufacturer STEP
    shows the problem is worse than a missing joint: the receiving part is a
    different form, in a different place, with the wrong opening.
    Measured on NAUO45 (input shaft hub), in assembled centred mm:
    - Body of revolution about the motor axis, z -9.25 to +5.25, Ø44.5 envelope,
    3114.2 mm3, not an outboard disc.
    - Six-spoke flange r 17.145 to 22.25 over z -1.75 to +0.25, so a 2 mm web with a
    Ø35.5 annular pocket; bores of Ø12 (front counterbore), Ø5.95, Ø4 and Ø6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
2026-09-18 Implement the measured rotor hub and reverse the stator axial shift
    Step 6 previously had no solution: assembly step A06 claimed to attach the input
    hub to a rotor end bell while no attachment geometry, retention or torque path
    existed. This implements the solution that the hub measurement supports.
    Measured drive interface, which the earlier audit understated. Sectioning the sun
    across the hub contact band and classifying each section resolves the open
    question of what drives the sun:
    - contact volume 0.324 mm3, confined to z 3.750..5.250 mm
    - sun front journal O6.000 into the hub counterbore O5.950
    - one section loop across that band with a 0.2022 mm azimuthal radius spread,
    i.e. a key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
    [main-housing-supported.step, oem-rotor-hub.step, provisional-planet-gear.step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]
2026-09-18 Restore a rotor carrier so the magnet-bond step is readable
    Step 5 showed only 42 loose magnets. That was my regression: the previous commit
    deleted the procedural EM03/endbell and EM03/yoke without replacing the rotor
    shell, so the magnet-bond step had no receiving part, and steps 5 to 7 still named
    the deleted geometry.
    Root cause of the deletion, now resolved with a measured carrier. The manufacturer
    hub's flange ends at r 22.25 mm and the nearest housing wall is at r 47.4 mm, so
    nothing in the source CAD joins the hub to the magnets. Sizing against the real
    housing shows why the old shell could never work: the main housing's inward wall is
    conical, r 44.050 mm at z -4.31 rising to r 47.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
2026-09-18 Audit all 20 assembly steps and find four real defects
    Adds the contact audit the handoff said had never been done: every stage checked
    for receiving parts, real contact, undefined joints, penetration and access, in
    both directions. Zero overlap alone cannot tell a seated joint from a floating
    part, so cad/check_assembly_contacts.py measures interference volume AND minimum
    distance for each claimed joint.
    Findings: 1 critical, 3 major, 4 blocked steps.
    CRITICAL - A03: the ring is not clamped. The eight front screws engage 0.0000 mm3
    of ring material. Ring flange top z 8.750 mm against screw tips z 9.950 mm, a
    1.200 mm gap. The ring and the stator it carries have no load path to the housing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
2026-09-18 Move the study rotor shell instead of the manufacturer hardware
    The previous commit moved the stator, winding, ring mounting flange and housing
    seat 4.5 mm rearward to align the stator with the magnet band. That moved
    manufacturer hardware and broke two things:
    - the eight front screws stayed at their fixed positions, so the ring clamp was
    destroyed: engagement measured 0.0000 mm3
    - the ring flange is generated from ring_z while the ring teeth live in the gear
    GLB at the gear plane, so the flange and its teeth separated by 2.000 mm
    Moving the ring instead is not available either: the ring's teeth would then
    overlap the planets by only 0.500 mm where a full 5.000 mm face is needed, whic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
    [main-housing-supported.step, provisional-planet-gear.step, provisional-ring-gear.step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]
2026-09-18 Rebuild the rotor end bell as one solid and add dimensioned part diagrams
    Two corrections, both prompted by comparing the model against the manufacturer
    arrangement.
    The rotor shell was split into two parts when the manufacturer makes it as one. The
    real part is a single spoked shell whose outer rim carries the magnets, with the sun
    force-fitted into it. The study had modelled a separate disc plus a separate rim,
    which invented a joint that did not exist and produced a 7.75 mm thick solid ring of
    43791 mm3: a solid-of-revolution shortcut, not a design.
    The shell is now one connected solid of 7482 mm3, built by cad/build_rotor_shell.py
    and checked as a single valid body:
    - six-spoke web on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
    [rotor-shell.step]
2026-09-18 Add an intersection test and fix the magnets cutting into the shell
    The project had no intersection test, and that was the root of every geometry
    regression so far: a hub with no attachment, a 43791 mm3 solid ring in place of a
    spoked shell, and magnets buried in the rim. All of it was one body passing through
    another, and no test caught any of it.
    cad/check_intersections.py now tests every pair of modelled bodies in the assembled
    state: 1225 pairs across 50 bodies, reporting interpenetration volume separately from
    whether a claimed joint actually touches. It runs as the first step of npm test, so
    npm test now fails when a body passes through another. A new npm run test:geometry
    runs the in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
    [rotor-shell.step]
2026-09-18 Build the rotor as one machined body and clear every blocked step
    The manufacturer photograph settles the architecture: the shell's web flows straight
    into the central hub boss, with the sun pressed into it. The hub and the shell are one
    machined part. Every earlier revision modelled them as two bodies and then argued
    about how to join them, which invented a joint the manufacturer does not have and
    produced the whole A06 blocker.
    cad/build_rotor.py takes the measured OEM hub (occurrence NAUO45) as the starting point
    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
    [rotor.step]
2026-09-18 Put the magnet bondline inside the rotor and stop viewer geometry drifting
    The reporter saw the magnet adhesive rendered as a gold ring outside the rotor. It was:
    C02 was hardcoded at r 42.45-42.50, which was correct for an earlier magnet band but lay
    outside the rotor once the band moved.
    Root cause is a class of defect, not one number. Several viewer meshes derive their radii
    and z from the rotor, and each was written out by hand in src/assembly-model.js, so every
    rotor rebuild silently invalidated them. Three such drifts had accumulated.
    Fixes:
    - cad/build_rotor.py now states every radial and axial band once, asserts they are
    strictly increasing and non-overlapping, and asserts the c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
    [rotor.step]
2026-09-18 Build the rotor to seat on the measured hub and bolt to its own hole circle
    Joint data is measured from the hub solid NAUO45 rather than assumed:
    seat spigot R 17.700 (D 35.40), z -1.75..+0.25
    flange face R 22.250 (D 44.50) outer edge, z -1.75..+0.25
    hole circle R 20.000 (D 40.00 PCD), hole D 2.05, azimuths 0/45/90..315
    The rotor is one machined solid: a flange bored D 35.50 to socket onto the hub spigot,
    eight D 2.20 clearance holes with D 4.00 countersinks on that same PCD, and a cup whose
    rim bore carries the magnets. Bounding D 86.4 x 13.7 mm, 9077 mm3, one valid solid.
    Measured: 0.000 mm3 against the main housing, the rear housing, the hub and the magnets;
    2.676 mm3 of fl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
    [rotor-flange.step]
2026-09-18 Wire the measured hub and the rotor into the viewer as two separate parts
    The rotor had been built as an asset but never loaded, which is why a refresh showed
    nothing. Both parts are now in the viewer and selectable:
    G03 the measured hub (NAUO45), one glTF solid
    EM03 the rotor (rotor-flange.glb), a separate machined part
    Splitting them restores the joint that an earlier revision dissolved by fusing the two
    into a single body.
    Corrected part descriptions: the hub's mounting circle is EIGHT holes of D 2.05 at
    D 40.00 PCD, not sixteen. The sixteen azimuths previously reported at that radius are
    spoke-pocket fillet faces, not holes. Measured hole patterns now recorded for every
    occurrenc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
2026-09-18 Rebuild the rotor as a spoked shell that slides over the hub and bolts to its face
    The shell now follows the arrangement shown in the reference image: a magnet rim, six
    spokes running inward, and a central boss that locates on the hub.
    Measured hub interfaces it mates with:
    slide-over surface hub flange R 22.250 (D 44.50), z -1.75..+0.25
    landing face hub flange face z +0.25
    locating collar D 14.00, z +0.25..+1.25
    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
    [rotor-shell.step]
2026-09-18 Fix the shell/bearing collision and make one file the source of the magnets
    The reporter saw magnets on the far side of the rotor. The cause was mine and structural:
    two builders each wrote geometry the viewer reads. cad/build_rotor.py wrote
    viewer-rotor-params.json while cad/build_rotor_shell.py built the shell actually displayed,
    so the magnets on screen stayed at r 41.2..42.2 after the shell moved to r 42.0..43.0. Every
    check read the same stale file as the viewer, so all of them reported zero while the visible
    model was wrong.
    - cad/build_rotor_shell.py is now the single source. It writes viewer-rotor-params.json, so
    the viewer and cad/check_intersections.py read the geometry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
    [rotor-shell.step]
2026-09-18 Match the shell bore to the hub flange and add a solid ring before the spokes
    Both changes requested by the reporter:
    - shell bore reduced from D 44.70 to D 44.50, matching the measured hub flange OD exactly,
    so the shell locates on the hub's outside rather than floating 0.1 mm clear
    - SPOKE_START_R added at r 25.25, giving a 3.00 mm solid ring of shell between the bore
    and the first spoke; the spokes now run from r 25.25 out to the rim at r 43.40, with an
    assertion that the ring is at least 2 mm
    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
    [rotor-shell.step]
